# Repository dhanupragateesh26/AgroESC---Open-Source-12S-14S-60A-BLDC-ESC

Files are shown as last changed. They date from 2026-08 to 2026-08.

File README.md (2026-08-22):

# AgroESC

### 12S–14S 60A Sensorless BLDC ESC for Agricultural Drones

<p align="center">
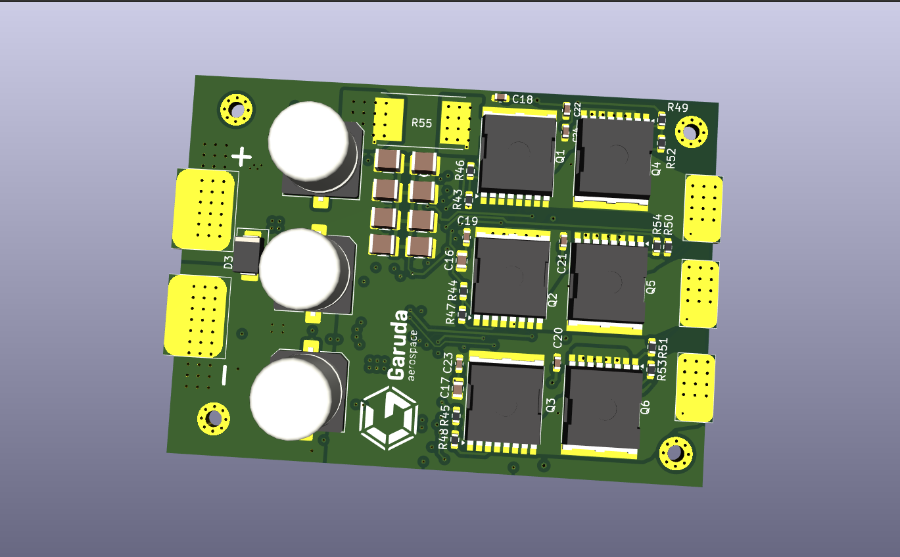
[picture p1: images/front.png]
  
</p>

<p align="center">
  <b>STM32F051 · DRV8300 · IPT015N10N5 · DShot · Sensorless BEMF · AM32</b>
</p>

---

## Overview

**AgroESC** is a high-voltage, high-current sensorless BLDC Electronic Speed Controller designed for agricultural drones, heavy-lift multirotors, and other high-power UAV applications.

The ESC is designed for **12S–14S LiPo batteries** with a **60A continuous current target**.

The hardware is based on an **STM32F051** microcontroller, **DRV8300** three-phase gate driver, and six **IPT015N10N5** power MOSFETs.

The ESC uses **sensorless six-step BLDC commutation** with Back-EMF rotor-position detection and communicates with the flight controller using **DShot**.

The hardware is designed for compatibility with **AM32 firmware**.

---

## Features

- 12S–14S LiPo operation
- 60A continuous current design target
- Sensorless BLDC operation
- Six-step commutation
- Back-EMF rotor-position detection
- DShot flight-controller interface
- STM32F051 MCU
- DRV8300 three-phase gate driver
- 6 × IPT015N10N5 power MOSFETs
- Low-side current sensing
- Battery-voltage monitoring
- Temperature monitoring
- High-voltage buck power supply
- 12V gate-drive supply
- 3.3V logic supply
- AM32 firmware support
- Designed for forced-air / PCB thermal cooling

---

## Electrical Specifications

| Parameter | Specification |
|---|---|
| Battery | 12S–14S LiPo |
| 12S nominal voltage | 44.4 V |
| 14S nominal voltage | 51.8 V |
| Maximum battery voltage | 58.8 V |
| Continuous current target | 60 A |
| Motor | 3-phase BLDC |
| Commutation | Sensorless six-step |
| Rotor position | Back-EMF |
| MCU | STM32F051 |
| Gate driver | DRV8300 |
| Power MOSFET | IPT015N10N5 |
| MOSFET count | 6 |
| FC protocol | DShot |
| Firmware | AM32 |
| Logic voltage | 3.3 V |
| Gate-drive voltage | 12 V |

> 60A continuous and 12S–14S operation are design targets and require experimental validation on assembled hardware.

---

## System Architecture

```text
                    ┌────────────────────┐
                    │  Flight Controller │
                    └─────────┬──────────┘
                              │
                            DShot
                              │
                              ▼
                     ┌─────────────────┐
                     │   STM32F051     │
                     │                 │
                     │  AM32 Firmware  │
                     └───────┬─────────┘
                             │
                             │ PWM
                             ▼
                     ┌─────────────────┐
                     │     DRV8300    │
                     │   Gate Driver  │
                     └───────┬─────────┘
                             │
                             ▼
                  ┌──────────────────────┐
                  │   3-Phase Power      │
                  │       Stage          │
                  │                      │
                  │  6 × IPT015N10N5     │
                  └──────────┬───────────┘
                             │
                        U / V / W
                             │
                             ▼
                        BLDC Motor
```

# Firmware

## AM32

The ESC is designed around the **AM32 open-source ESC firmware**.

AM32 provides the main motor-control functionality, including:

- DShot command processing
- Six-step commutation
- PWM generation
- Sensorless BEMF detection
- Startup and motor ramping
- Motor timing control
- Current/voltage monitoring
- ESC telemetry
- Configuration and protection features

The exact firmware configuration depends on the MCU pin mapping and hardware implementation of the ESC.

> The AgroESC hardware requires an AM32 firmware target/configuration that matches the STM32F051 pin mapping used in this design (Group B).

---

## Firmware Loading

The ESC includes an **SWD programming interface** for initial firmware flashing and development.

The STM32F051 can be programmed using an **ST-LINK** debugger/programmer.

### SWD Connections

| ESC Pin | ST-LINK |
|---|---|
| 3.3V | 3.3V |
| GND | GND |
| SWDIO | SWDIO |
| SWCLK | SWCLK |
| NRST | NRST |

### Initial Firmware Flashing

For initial programming:

1. Connect an ST-LINK to the ESC SWD header.
2. Power the MCU/ESC logic section with the appropriate supply.
3. Connect the ST-LINK to the STM32F051.
4. Build or obtain the appropriate AM32 firmware binary.
5. Flash the firmware to the STM32 using an SWD programming tool.
6. Verify that the MCU starts correctly.
7. Configure the ESC parameters using the appropriate AM32 configuration interface.
8. Connect the ESC signal wire to the flight controller.
9. Test DShot communication **without a propeller installed**.

The SWD interface is useful for:

- Initial firmware installation
- Firmware recovery
- Debugging
- Development
- Firmware updates

---

# PCB Design

The PCB layout was designed with emphasis on **high-current and high-frequency switching performance**.

Key design considerations include:

- Low-inductance power paths
- Short MOSFET gate-drive loops
- Short switching-current loops
- Proper DC bus capacitor placement
- Kelvin current-sense routing
- High-current copper planes
- Thermal copper spreading
- Thermal vias
- Controlled switch-node areas
- Separation of analog and high-frequency switching signals
- Short DRV8300-to-MOSFET connections
  
<p align="center">
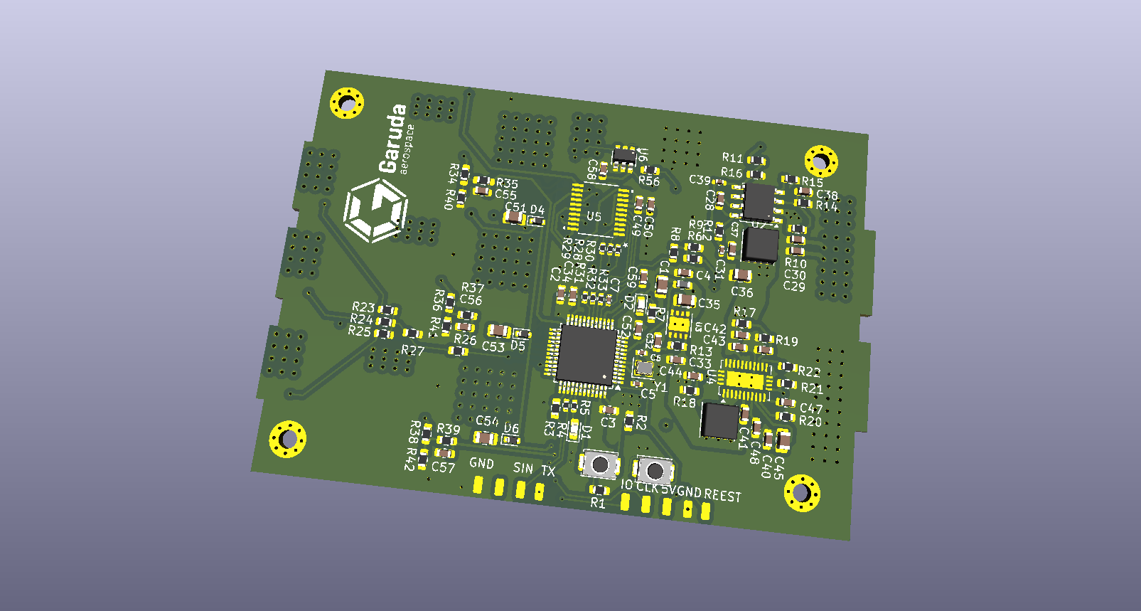
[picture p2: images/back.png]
  
</p>

# Applications

AgroESC is intended for:

- Agricultural drones
- Heavy-lift multirotors
- High-power UAVs
- Large BLDC motors
- Custom drone propulsion systems

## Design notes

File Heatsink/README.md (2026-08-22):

# Heatsink Design & Thermal Analysis

This folder contains the **heatsink design and thermal analysis** developed for the AgroESC power stage.

The heatsink was designed to manage the thermal load generated by the ESC power MOSFETs during high-current operation, with particular focus on the **60A continuous design target**.

---

## Overview

The thermal design process included:

- Heatsink mechanical design
- Thermal analysis
- Transient thermal analysis
- Convection analysis
- Finite Element Analysis (FEA)
- Heatsink performance comparison
- Thermal behavior during representative operating conditions

The objective was to develop a heatsink capable of effectively transferring heat from the MOSFET power stage to the surrounding airflow while maintaining acceptable component temperatures.

---

## Heatsink Design

The final heatsink geometry was designed considering:

- Available PCB space
- MOSFET mounting locations
- Thermal contact area
- Fin geometry
- Fin spacing
- Surface area
- Airflow
- Weight
- Manufacturability

### Heatsink Design

<p align="center">
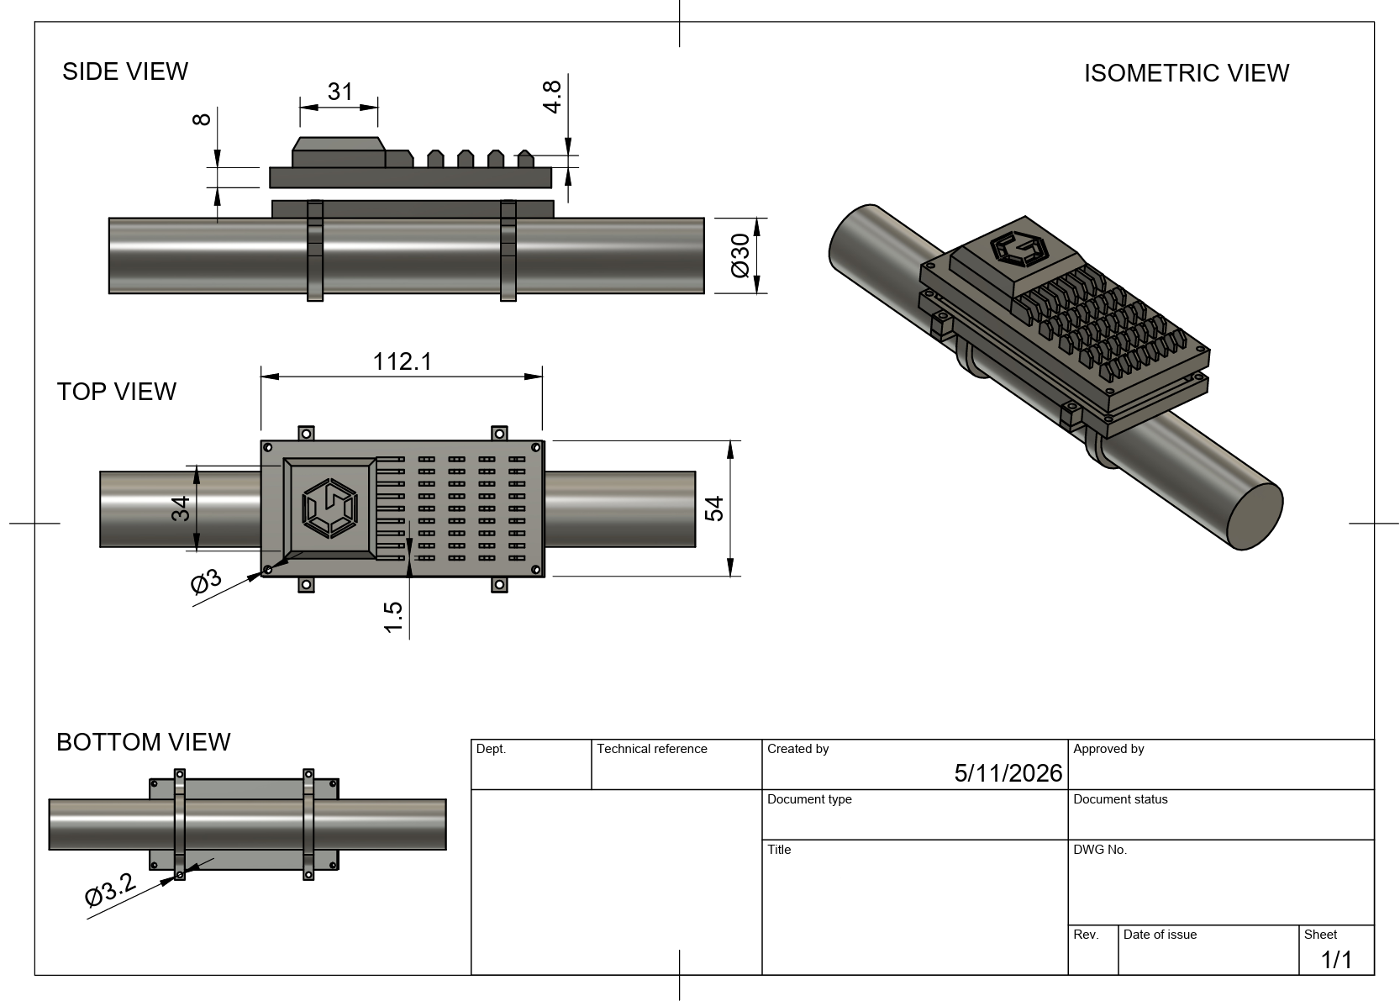
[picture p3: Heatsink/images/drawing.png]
  
</p>

---

# Thermal Analysis

Several thermal simulations were performed to evaluate the heatsink under different operating conditions.

The analysis includes both **steady-state and transient thermal behavior**, allowing the heatsink performance to be evaluated during continuous operation as well as changing thermal loads.

## FEA Thermal Analysis

Finite Element Analysis (FEA) was performed to study the thermal distribution and identify potential hot spots within the heatsink.

<p align="center">
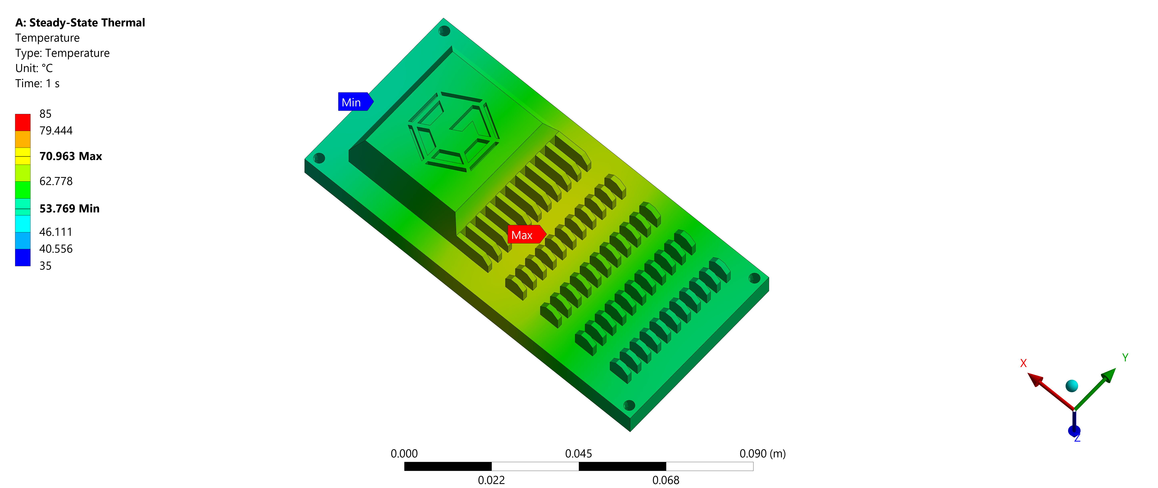
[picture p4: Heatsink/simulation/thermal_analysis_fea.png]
  
</p>

---

## Transient Thermal Analysis

Transient analysis was performed to observe how the heatsink temperature changes with time from the initial thermal condition.

<p align="center">
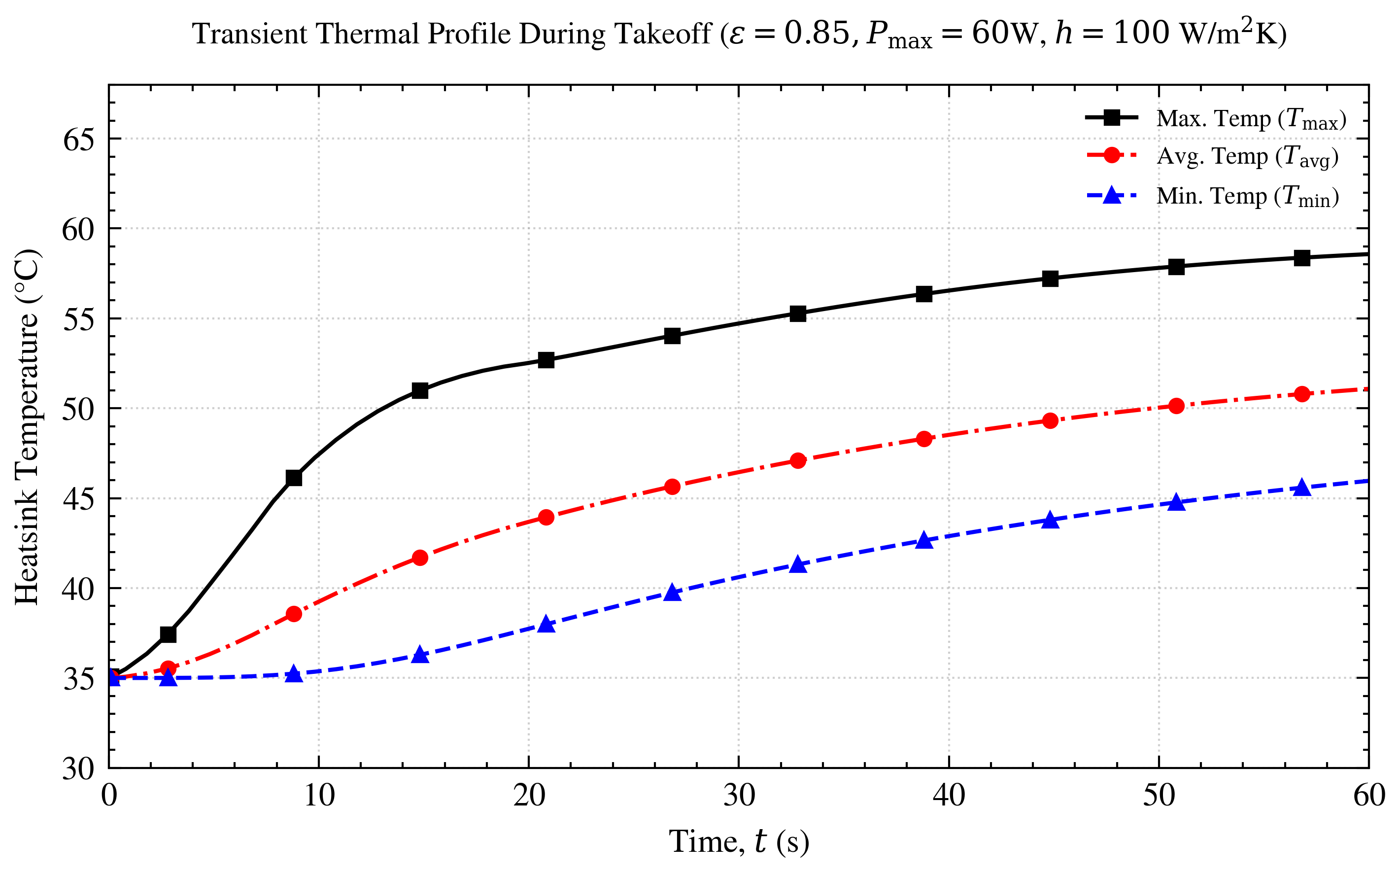
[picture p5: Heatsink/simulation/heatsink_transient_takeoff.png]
  
</p>

This helps evaluate:

- Initial temperature rise
- Thermal response time
- Heat accumulation
- Temperature stabilization
- Transient behavior during changing loads

---

## Convection Comparison

Different convection conditions were analyzed to understand the effect of airflow on heatsink performance.

<p align="center">
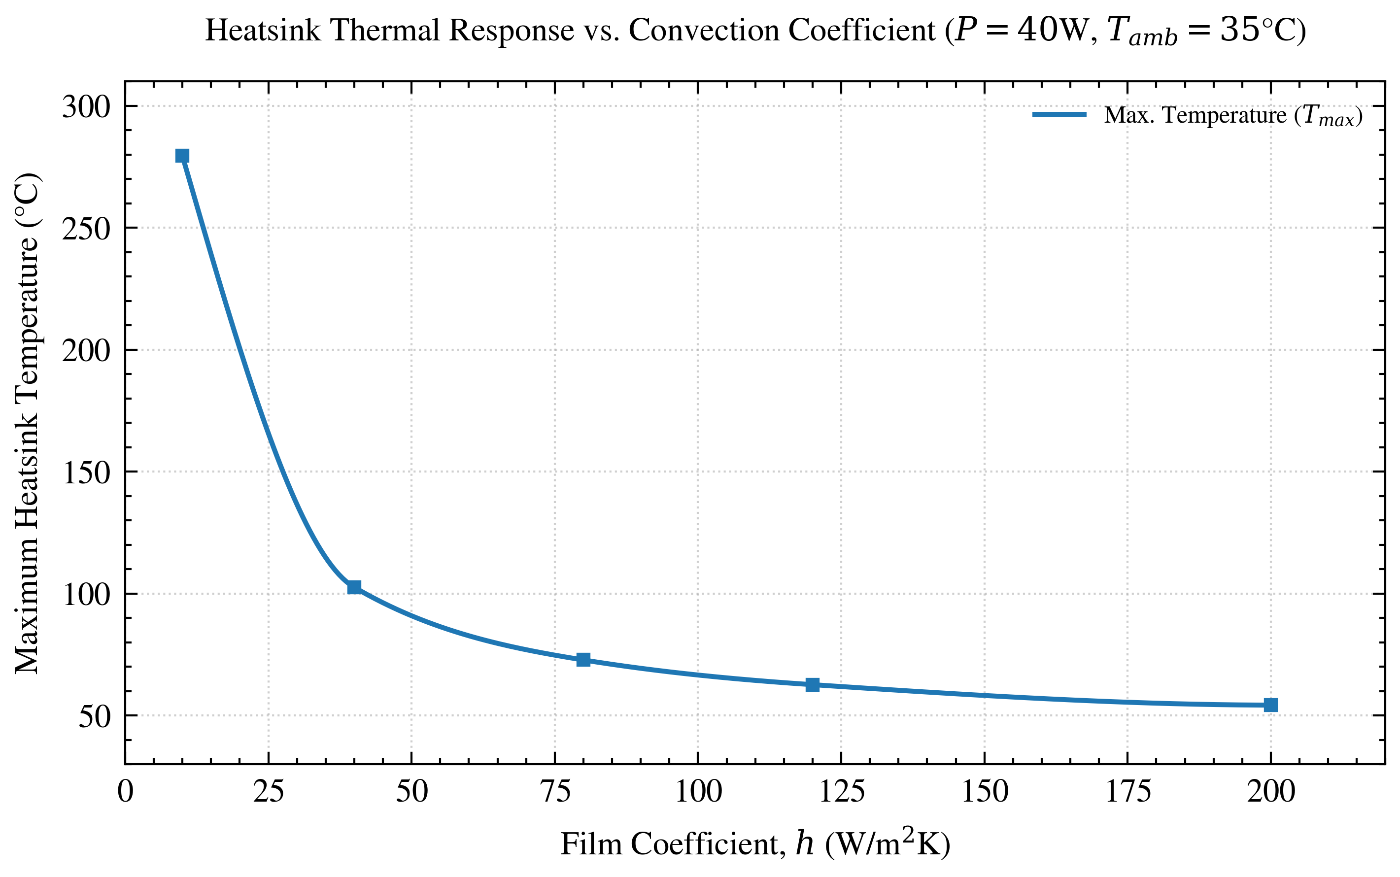
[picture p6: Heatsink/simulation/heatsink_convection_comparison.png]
  
</p>

The comparison helps determine the influence of airflow and convection coefficient on:

- Maximum heatsink temperature
- Temperature distribution
- Heat dissipation
- Thermal equilibrium

---

# Thermal Design Considerations

The heatsink design focuses on improving heat transfer through:

- Increased surface area
- Extended fin geometry
- Improved convection
- Reduced thermal resistance
- Efficient thermal coupling to the power stage
- Utilization of drone propeller airflow

For an agricultural drone ESC, airflow generated by the propellers can provide significant forced convection during operation.

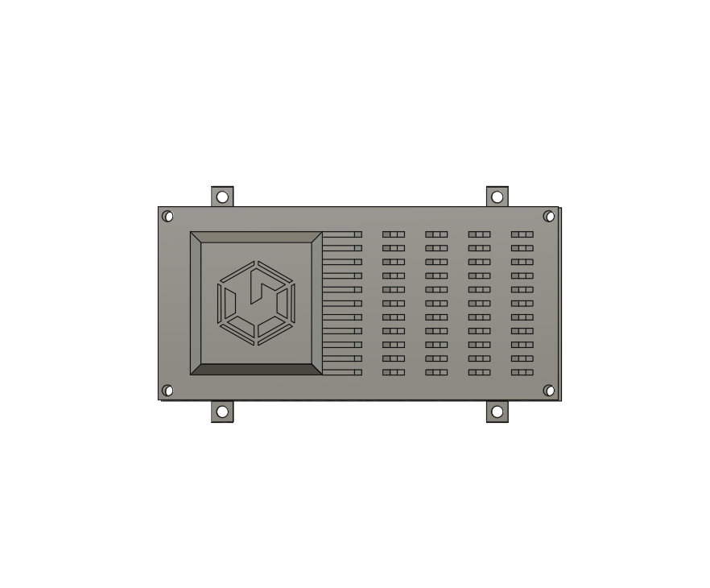
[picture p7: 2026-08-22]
Heatsink/simulation/heatsink_design.png

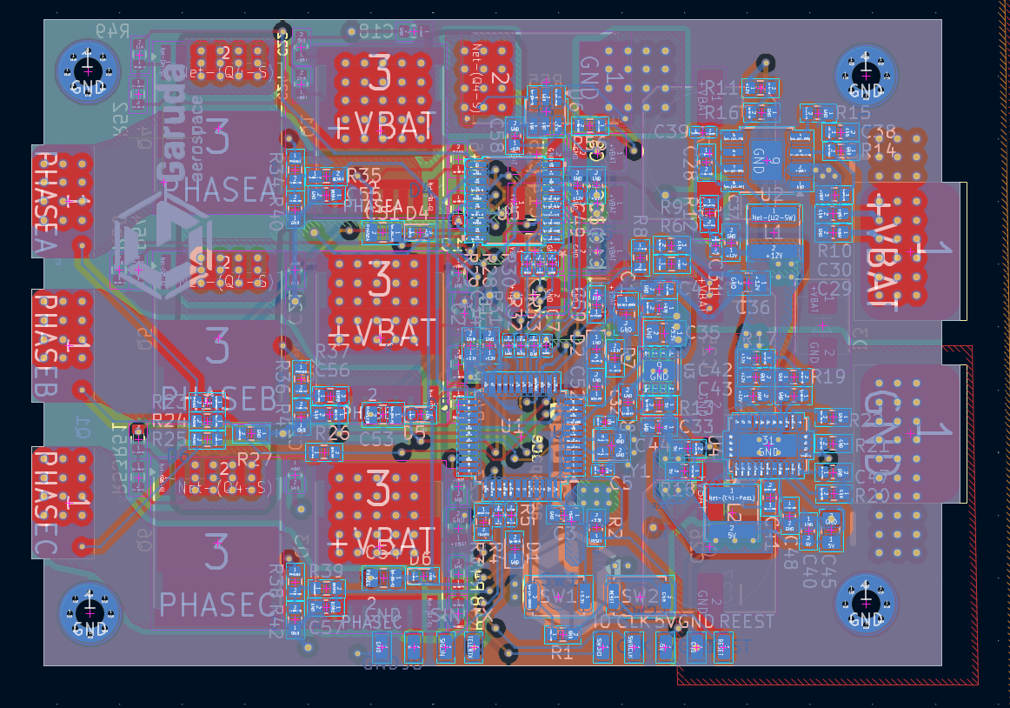
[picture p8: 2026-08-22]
images/layout_back.png

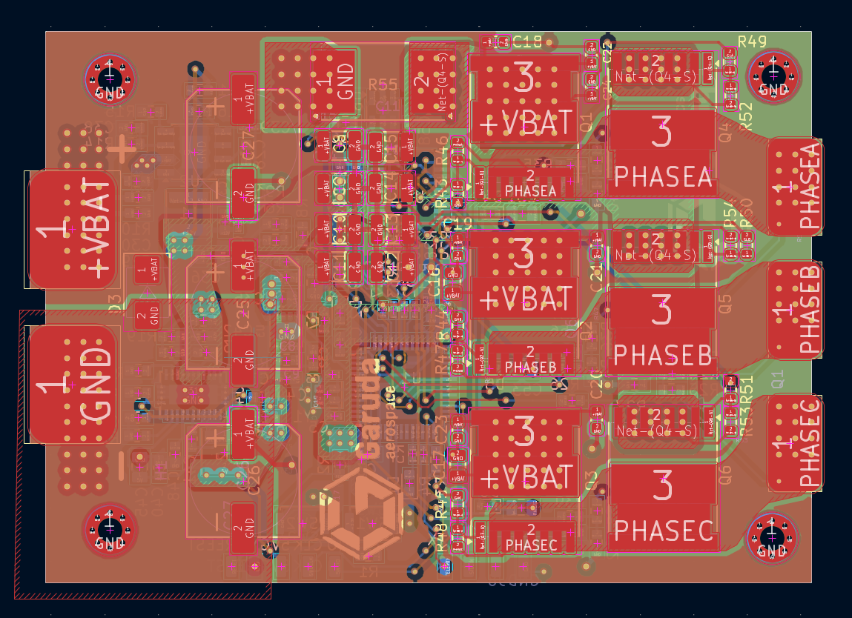
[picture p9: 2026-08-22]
images/layout_front.png

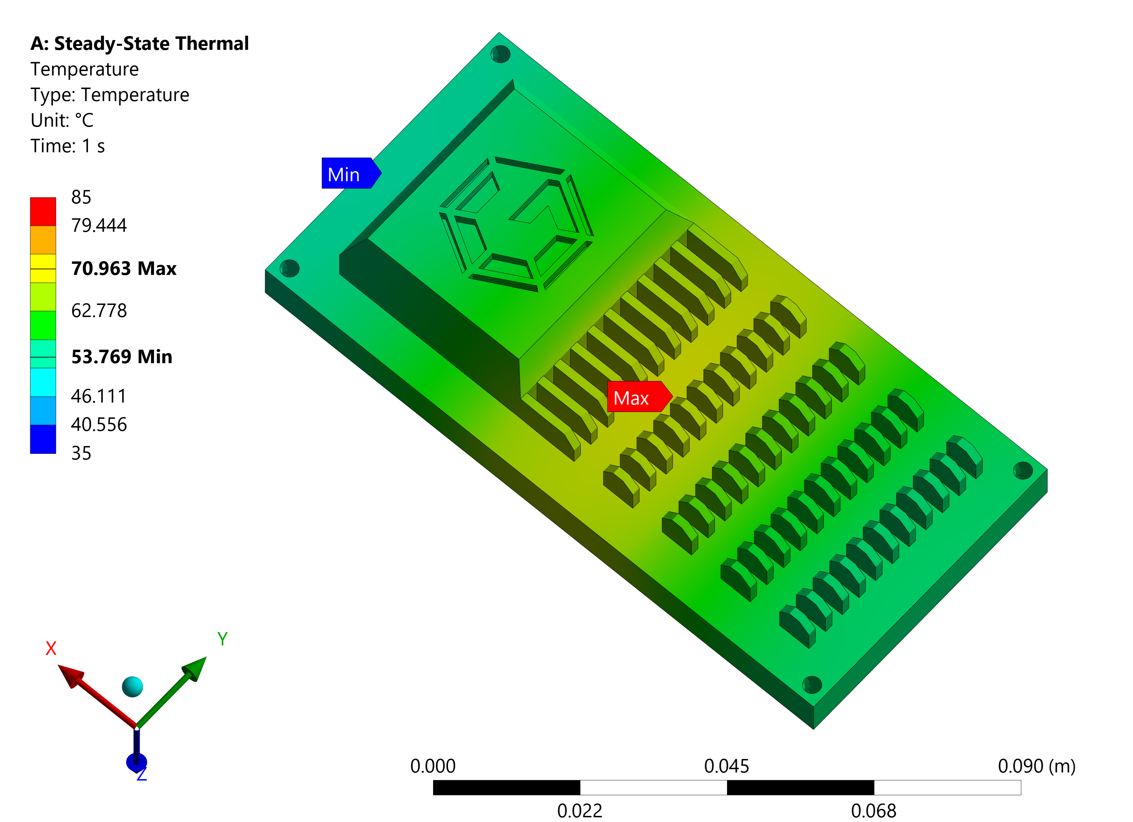
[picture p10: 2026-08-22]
Heatsink/simulation/thermal_analysis.png

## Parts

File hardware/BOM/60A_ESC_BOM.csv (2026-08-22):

Reference | Qty | Value | DNP | Exclude from BOM | Exclude from Board | Footprint | Datasheet
C1 | 1 | 1u |  |  |  | Capacitor_SMD:C_0805_2012Metric
C2,C28,C47 | 3 | 10n |  |  |  | Capacitor_SMD:C_0603_1608Metric
C3,C4,C19,C20,C21,C22,C23,C24,C30,C32,C37,C38,C40,C41,C43,C44,C46,C48,C50,C58 | 20 | 100n |  |  |  | Capacitor_SMD:C_0603_1608Metric
C5,C6 | 2 | 22p |  |  |  | Capacitor_SMD:C_0402_1005Metric
C7 | 1 | 1n |  |  |  | Capacitor_SMD:C_0402_1005Metric
C8,C9,C10,C11,C12,C13,C14,C15 | 8 | 10u |  |  |  | Capacitor_SMD:C_1210_3225Metric
C16,C17 | 2 | 10u |  |  |  | Capacitor_SMD:C_0805_2012Metric
C18 | 1 | 10u |  |  |  | Capacitor_SMD:C_0603_1608Metric
C25,C26,C27 | 3 | 300u |  |  |  | Capacitor_SMD:C_Elec_10x10.2
C29,C42 | 2 | 2.2u |  |  |  | Capacitor_SMD:C_0603_1608Metric
C31 | 1 | 3.3n |  |  |  | Capacitor_SMD:C_0402_1005Metric
C33,C34,C49 | 3 | 1u |  |  |  | Capacitor_SMD:C_0603_1608Metric
C35 | 1 | 4.7u |  |  |  | Capacitor_SMD:C_0805_2012Metric
C36 | 1 | 47u |  |  |  | Capacitor_SMD:C_0805_2012Metric
C39 | 1 | 56p |  |  |  | Capacitor_SMD:C_0402_1005Metric_Pad0.74x0.62mm_HandSolder
C45 | 1 | 22u |  |  |  | Capacitor_SMD:C_0805_2012Metric
C51,C53,C54 | 3 | 100n |  |  |  | Capacitor_SMD:C_0805_2012Metric
C52,C55,C56,C57,C59 | 5 | 1n |  |  |  | Capacitor_SMD:C_0603_1608Metric
D1,D2 | 2 | LED |  |  |  | LED_SMD:LED_0603_1608Metric
D3 | 1 | SMCJ75A |  |  |  | Diode_SMD:D_SMB | https://www.vishay.com/docs/88303/15smc.pdf
D4,D5,D6 | 3 | ES1J |  |  |  | Diode_SMD:D_SOD-523 | http://www.mouser.com/ds/2/149/1N4148WT-461550.pdf
FB1 | 1 | FerriteBead |  |  |  | Inductor_SMD:L_0603_1608Metric
J1 | 1 | 3.3v |  |  |  | Connector_Wire:SolderWirePad_1x01_SMD_1x2mm
J2,J7 | 2 | gnd |  |  |  | Connector_Wire:SolderWirePad_1x01_SMD_1x2mm
J3 | 1 | swio |  |  |  | Connector_Wire:SolderWirePad_1x01_SMD_1x2mm
J4 | 1 | swclk |  |  |  | Connector_Wire:SolderWirePad_1x01_SMD_1x2mm
J5 | 1 | reset |  |  |  | Connector_Wire:SolderWirePad_1x01_SMD_1x2mm
J6 | 1 | Telem |  |  |  | Connector_Wire:SolderWirePad_1x01_SMD_1x2mm
J8 | 1 | nc |  |  |  | Connector_Wire:SolderWirePad_1x01_SMD_1x2mm
J9 | 1 | sigin |  |  |  | Connector_Wire:SolderWirePad_1x01_SMD_1x2mm
J10 | 1 | +_in |  |  |  | SolderPads:Pad_11x9mm
J11 | 1 | -_in |  |  |  | SolderPads:Pad_11x9mm
J12 | 1 | A out |  |  |  | SolderPads:Pad_9x5mm
J13 | 1 | B out |  |  |  | SolderPads:Pad_9x5mm
J14 | 1 | C out |  |  |  | SolderPads:Pad_9x5mm
L1 | 1 | 68u |  |  |  | Inductor_SMD:L_Changjiang_FNR4020S
L2 | 1 | 6/8u |  |  |  | Inductor_SMD:L_Changjiang_FNR4020S
Q1,Q2,Q3,Q4,Q5,Q6 | 6 | IPT015N10N5 |  |  |  | Package_TO_SOT_SMD:Infineon_PG-HSOF-8-1 | http://www.infineon.com/dgdl/Infineon-IPT015N10N5-DS-v02_01-EN.pdf?fileId=5546d4624a75e5f1014ac94680661aff
R1,R2,R9,R19,R22,R27,R40,R41,R42,R46,R47,R48,R52,R53,R54 | 15 | 10k |  |  |  | Resistor_SMD:R_0603_1608Metric
R3,R43,R44,R45,R49,R50,R51 | 7 | 4R7 |  |  |  | Resistor_SMD:R_0603_1608Metric
R4,R28,R29,R30,R31,R32,R33 | 7 | 33 |  |  |  | Resistor_SMD:R_0402_1005Metric
R5 | 1 | 200 |  |  |  | Resistor_SMD:R_0402_1005Metric
R6,R23,R24,R25,R36,R38 | 6 | 220k |  |  |  | Resistor_SMD:R_0603_1608Metric
R7 | 1 | 200 |  |  |  | Resistor_SMD:R_0603_1608Metric
R8,R26,R37,R39,R56 | 5 | 100 |  |  |  | Resistor_SMD:R_0603_1608Metric
R10 | 1 | 1M |  |  |  | Resistor_SMD:R_0603_1608Metric
R11,R12 | 2 | 453k |  |  |  | Resistor_SMD:R_0603_1608Metric
R13,R15,R17,R18 | 4 | 100k |  |  |  | Resistor_SMD:R_0603_1608Metric
R14 | 1 | 33k |  |  |  | Resistor_SMD:R_0603_1608Metric
R16,R20 | 2 | 49.9k |  |  |  | Resistor_SMD:R_0603_1608Metric
R21 | 1 | 25k |  |  |  | Resistor_SMD:R_0603_1608Metric
R34 | 1 | 220k |  |  |  | Resistor_SMD:R_0603_1608Metric_Pad0.98x0.95mm_HandSolder
R35 | 1 | 100 |  |  |  | Resistor_SMD:R_0603_1608Metric_Pad0.98x0.95mm_HandSolder
R55 | 1 | 1m |  |  |  | Resistor_SMD:R_Shunt_Vishay_WSR2_WSR3_KelvinConnection
SW1 | 1 | BOOT |  |  |  | Button_Switch_SMD:SW_Push_SPST_NO_Alps_SKRK
SW2 | 1 | RESET |  |  |  | Button_Switch_SMD:SW_Push_SPST_NO_Alps_SKRK
U1 | 1 | STM32F051C6Tx |  |  |  | Package_QFP:LQFP-48_7x7mm_P0.5mm | https://www.st.com/resource/en/datasheet/stm32f051c6.pdf
U2 | 1 | LM5164DDA |  |  |  | Package_SO:HSOP-8-1EP_3.9x4.9mm_P1.27mm_EP2.41x3.1mm | https://www.ti.com/lit/ds/symlink/lm5164.pdf?ts=1598311864250
U3 | 1 | TPS7A2150PQWDRBRQ1 |  |  |  | TPS7A2150PQWDRBRQ1:VREG_TPS7A2150PQWDRBRQ1
U4 | 1 | LM76005 |  |  |  | Package_DFN_QFN:Texas_RNP0030B_WQFN-30-1EP_4x6mm_P0.5mm_EP1.8x4.5mm | https://www.ti.com/lit/ds/symlink/lm76005.pdf
U5 | 1 | DRV8300NPWR |  |  |  | DRV8302:TSSOP_0DIPWR_TEX | https://www.ti.com/lit/gpn/drv8300
U6 | 1 | INA181 |  |  |  | Package_TO_SOT_SMD:SOT-23-6 | http://www.ti.com/lit/ds/symlink/ina181.pdf
Y1 | 1 | Crystal_GND23_Small |  |  |  | Crystal:Crystal_SMD_2016-4Pin_2.0x1.6mm

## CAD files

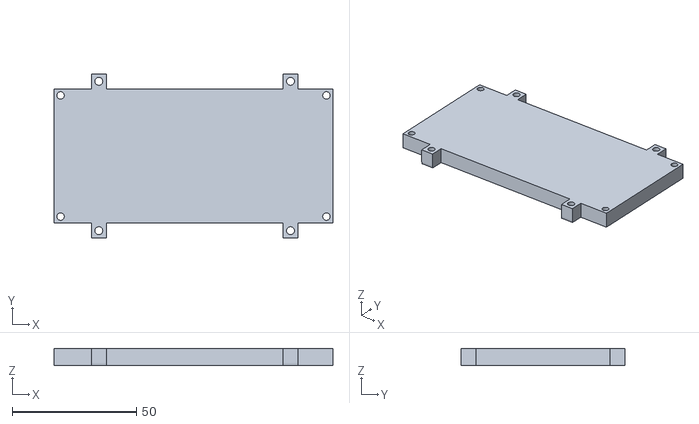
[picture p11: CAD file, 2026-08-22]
Heatsink/stil_files/escbottom.stl
112.1 x 66.0 x 7.00

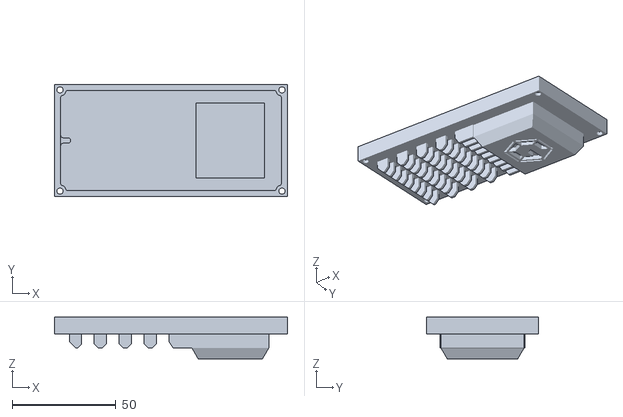
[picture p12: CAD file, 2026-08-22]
Heatsink/stil_files/esctop.stl
112.1 x 54.0 x 20.0

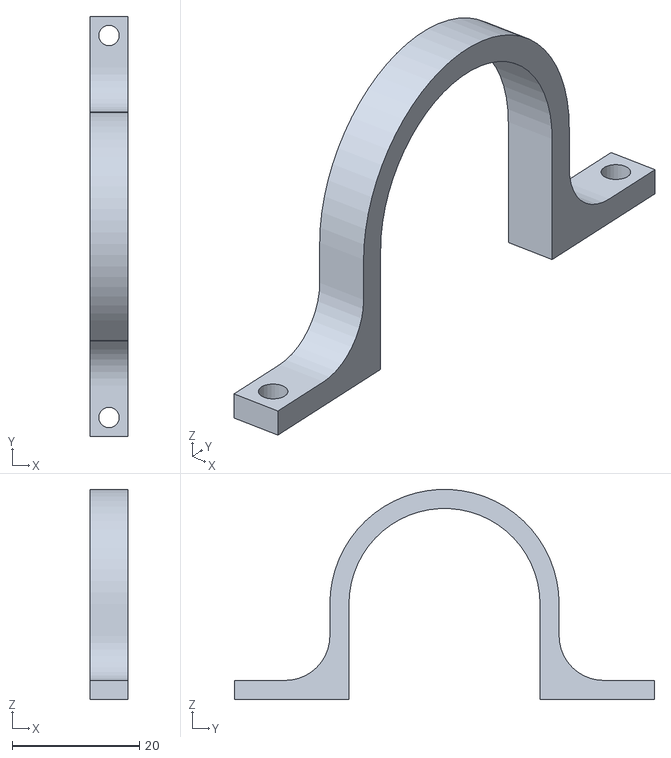
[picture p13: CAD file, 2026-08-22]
Heatsink/stil_files/clamp.stl
6.00 x 66.0 x 33.0

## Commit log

2026-08-22 Add schematic for 60A AM32 ESC
    This file defines the schematic for a 60A AM32 ESC with multiple sheets including MOSFET, GATE DRIVER, MCU_stm, and POWER.
    [ESC_v2.kicad_sch]
2026-08-22 Change ESC image in README
    Updated the image source in the README for better representation.
2026-08-22 Expand README with firmware and programming details
    Added detailed firmware information and loading instructions for the ESC, including AM32 firmware features and SWD programming steps.
